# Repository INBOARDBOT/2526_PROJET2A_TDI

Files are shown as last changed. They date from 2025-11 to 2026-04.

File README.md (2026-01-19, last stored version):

# 2526_PROJET2A_TDI
Total Drive Immersion - Motion System

The objective of this project is to create a 3 axis motion plateform for car racing simulations.
It consist of four linear actuators (with their respective [**drivers**](https://github.com/INBOARDBOT/2526_PROJET2A_TDI/tree/main/HARDWARE/PCB'S/FOC_CONTROLLER_V2)), a Nucleo Discovery which handle
the communication between the drivers and the computer as well as a touchscreen interface.
The data is sent from SimHub to the the Nucleo via UART. The position values are then distributed to each actuator via an [**RS485**](https://github.com/INBOARDBOT/2526_PROJET2A_TDI/tree/main/HARDWARE/PCB'S/COM_BOARD) bus.

# Achitecture logicielle

L'architecture logicielle est conçue de manière modulaire, segmentant les fonctionnalités du simulateur de conduite en plusieurs sous-systèmes spécialisés. Cette approche permet de séparer les responsabilités et de faciliter la maintenance du système. L'architecture s'articule autour de trois piliers principaux :

Couche Communication : Gère les protocoles d'échange de données entre l'unité centrale et les drivers de vérins (via le bus RS-485), garantissant l'intégrité et la rapidité des transmissions.

Module de Gestion des Actionneurs : Assure le traitement des commandes, le calcul des trajectoires des vérins et le monitoring de l'état des drivers.

Interface Graphique et IHM : Pilote le rendu visuel sur l'écran LCD-TFT et traite les interactions tactiles de l'utilisateur, tout en gérant les ressources stockées en mémoire Flash.

## Organistaion du projet
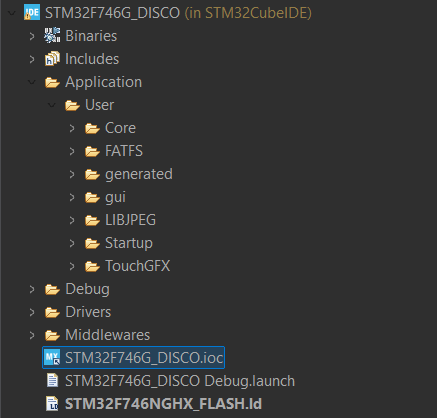
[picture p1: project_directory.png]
<br>
* `Application/` Contient la logique métier principale développée par l'utilisateur.
    * `gui/` et `generated/` Dédiés à l'interface graphique (typiquement pilotés par TouchGFX sur le F746G). Regroupe le backend (logique) et le frontend (assets et code généré).
    * `Core/` Noyau de l'application gérant la communication et la supervision de la centrale avec le reste du système de simulation.
* `Driver/` Regroupe les couches d'abstraction matérielle (BSP : gestion des composants externes). 
* `Debug/` Répertoire de sortie du compilateur.

## Présentation des Composants

### Unité Centrale
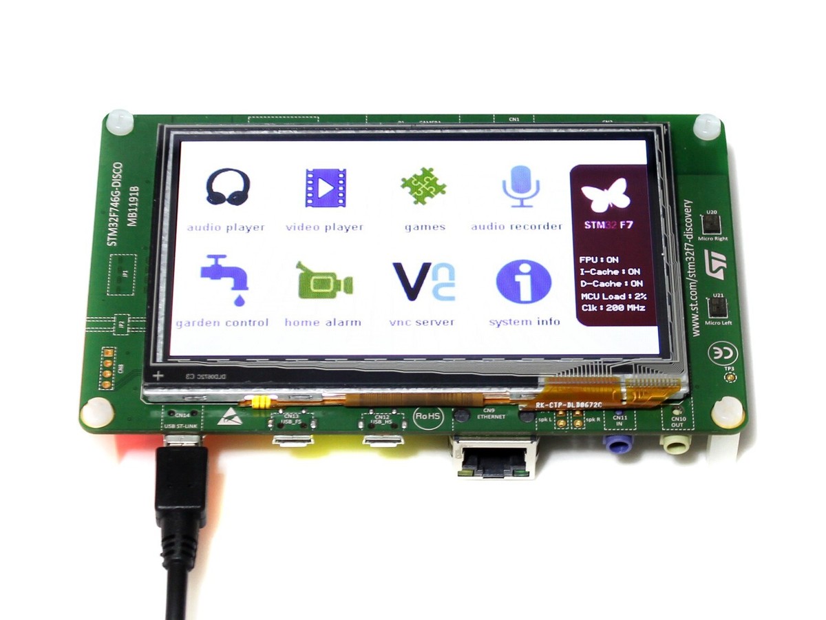
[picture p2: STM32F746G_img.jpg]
<br>
La centrale controle l'enssemble du systeme de simulation, elle doit etre reactive et embarquer une interface graphique servant d'IHM. Voici donc les principales fonctionnalites que la carte STM32F746G nous propose :
* Puissance de calcul : Architecture Arm Cortex STM32F746NGH6
* Interactions avec l'utilisateur (IHM) : Ecran tactile 4.3” RGB 480×272 color LCD-TFT
* Stockage des ressources graphiques lourdes commes les imges : 128-Mbit Quad-SPI Flash memory

Fonctionnalitees addiotionnelles petinentes :
* Gestion Audio intégrée : Audio line in and line out jack & Stereo speaker outputs

### Driver de vérin
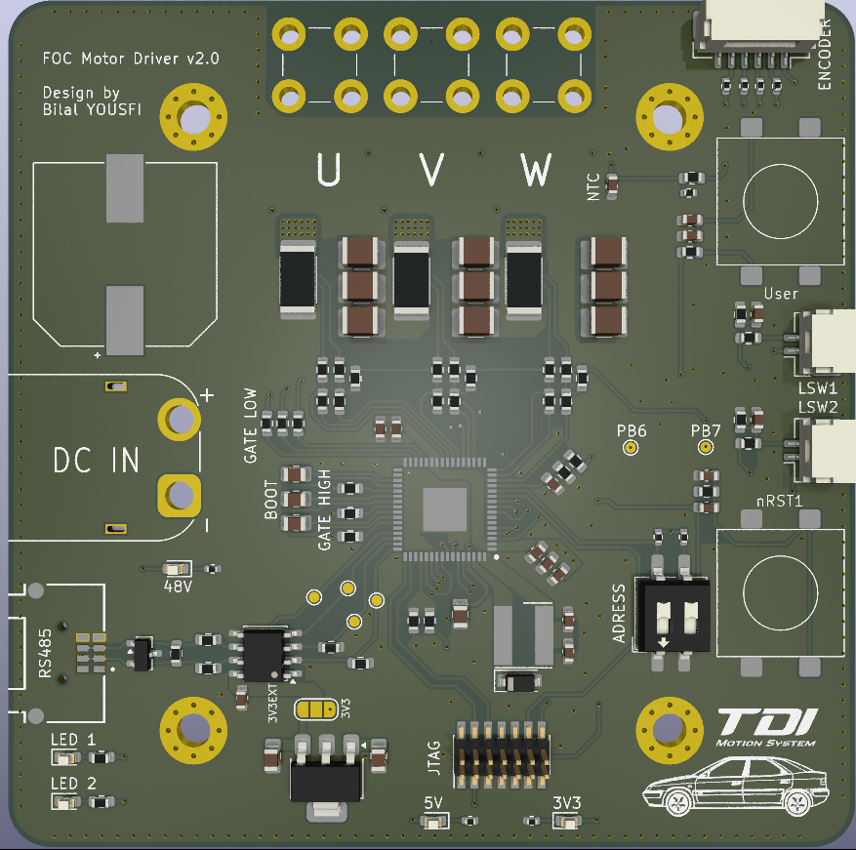
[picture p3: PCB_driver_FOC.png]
<br>
Les drivers des verrins permettent de faire l'interface entre les ordres transmis par la centrale et l'action entrepris par les verrins. 
Les drivers des verrins permettent de communiquer via le bus RS485 afin de recevoir les données de position et de renvoyer des informations sur l'etat de l'actionneur.Il est compose des elements suivants :
* STSPIN32G4: Gère les calculs d'asservissemntet  le controle de l'etage de puissance grâce a son driver de mosfet intégré.
* STL130N8F7: L'etage de puissance est composé de trois demi pont avec des N-MOS pouvant supporter jusqu'a 80V et 100A 
* THVD1420: Tranciever RS485 

### Interface de Communication (Bus RS-485)
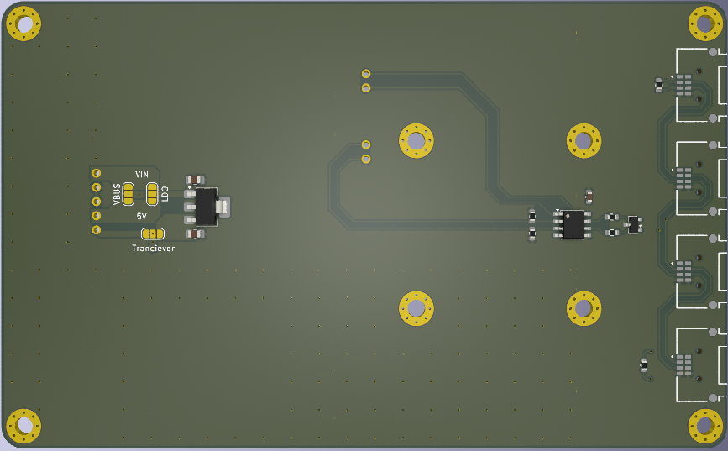
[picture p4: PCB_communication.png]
<br>
L'interface de communication est une carte électronique intermédiaire positionnée entre l'unité centrale et les différents actionneurs (vérins).

Pour surmonter la contrainte de la distance physique et garantir une transmission rapide et immunisée contre les parasites, la liaison s'appuie sur la norme RS-485. Ce standard utilise une signalisation différentielle particulièrement fiable en milieu industriel.

L'interface assure la conversion des signaux : elle transforme le protocole UART (TTL) de la centrale en signaux différentiels pour le bus, puis les drivers des vérins effectuent la conversion inverse pour traiter l'information. L'ensemble des drivers est raccordé en parallèle selon une topologie en bus, permettant une gestion simplifiée du câblage.

## Environnement de Développement
Le développement du projet repose sur une chaîne d'outils intégrée, permettant de gérer aussi bien la configuration matérielle que l'interface utilisateur et le versionnage du code.

`STM32CubeIDE` <br>
Il s'agit de l'environnement de développement (IDE) fourni par STMicroelectronics.

* Configuration : Intègre STM32CubeMX pour configurer graphiquement les périphériques (UART, RS-485, Horloges).

* Développement & Debug : Permet l'écriture du code en C/C++ et offre des outils de débogage avancés (lecture de registres en temps réel, analyseur de variables).

`TouchGFX Designer` <br>
Framework graphique avancé spécifiquement optimisé pour les microcontrôleurs STM32.

* Design UI : Permet de concevoir l'interface de manière visuelle pour ensuite developper en C++ dessus.

* CMSIS-RTOS : S'intègre avec FreeRTOS pour séparer le thread de rendu graphique des threads de communication et de calcul (Backend/Frontend).

* Generation du fichier du projet : Génére le code d'initialisation avec la configuration de l'interface graphique automatise (gros avantage de TouchGFX).

# Interface Graphique
<br>
L'interface graphique (IHM) permet de visualiser en temps réel l'état du système de simulation. Elle offre à l'utilisateur une plateforme interactive pour piloter le simulateur, lancer les procédures de calibration et ajuster les paramètres de conduite.

## TouchGFX Designer
TouchGFX Designer est l'outil utilisé pour concevoir l'environnement visuel. Il génère un code C++ optimisé qui tire parti des capacités d'accélération matérielle du STM32.

### Creation du projet
La première étape consiste à sélectionner le BSP (Board Support Package) correspondant à notre matériel : le `STM32F746G Discovery Kit`.<br>
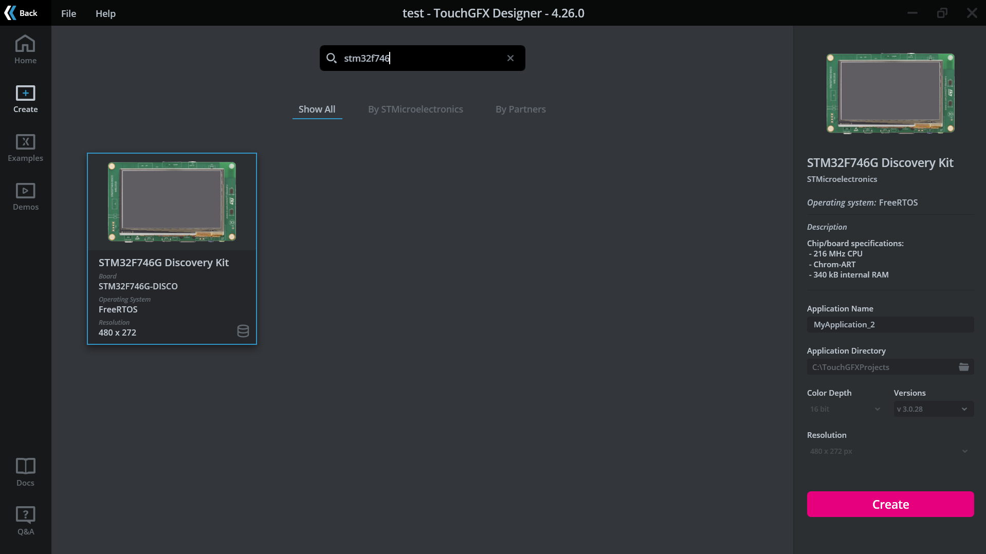
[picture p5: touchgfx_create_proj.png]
<br>

[!IMPORTANT] Cette étape est cruciale car TouchGFX génère non seulement l'interface, mais aussi toute la structure du projet (fichiers de configuration, drivers d'écran, gestion de la mémoire) que nous importerons ensuite dans STM32CubeIDE.

### Architecture de l'interface
L'interface est découpée en plusieurs Écrans (Screens). Chaque écran possède son propre fichier de vue (View) et son présentateur (Presenter), permettant de séparer la logique graphique de la logique métier.

#### Ecran
Les vues du simulateur
Pour garantir une navigation fluide, nous avons segmenté l'IHM en quatre écrans principaux :

* SimHubScreen : Le tableau de bord principal. Il affiche les données télémétriques en temps réel, telles que l'extension des vérins et la consommation électrique des drivers.

* LoadingScreen : Une interface de transition utilisée lors des processus lourds, typiquement durant la phase de calibration automatique des vérins.

* MenuScreen : Le point d'entrée central permettant à l'utilisateur de naviguer entre les différentes sections.

* SettingScreen : Un espace dédié à la configuration logicielle et matérielle du système.

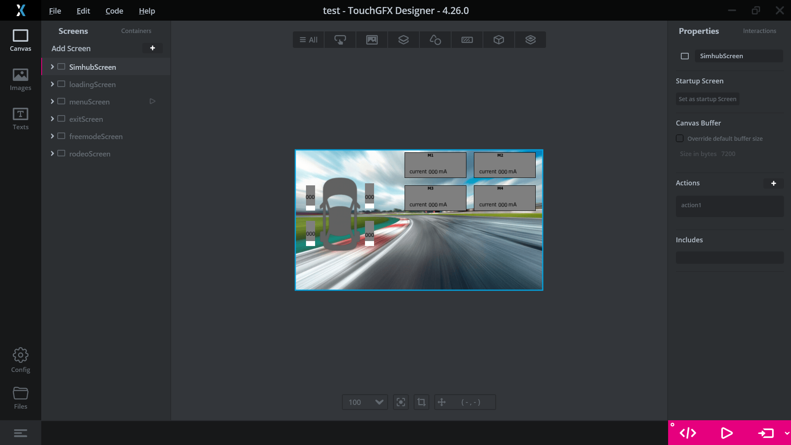
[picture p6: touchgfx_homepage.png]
<br>

Avoir une multitude d'ecran permet de faciliter le developpement des differents UI. 

#### Composants et Outils
L'IDE propose deux types de blocs de construction pour concevoir les écrans :

1. Les Widgets : Ce sont les éléments de base (boutons, zones de texte, jauges, formes géométriques). Ils sont entièrement personnalisables pour correspondre à la charte graphique du simulateur.

2. Les Conteneurs (Containers) : Ils permettent de regrouper plusieurs widgets au sein d'une même entité. Cela facilite la création de fenêtres modales, de listes déroulantes ou de menus complexes.

Vous pouvez retrouver ci-dessous la documentation sur les outils et conteneurs pour en apprendre d'avantages [Contenuer/Outil](https://support.touchgfx.com/docs/development/ui-development/working-with-touchgfx/widgets-and-containers)

### Generer le projet
Une fois le design finalisé, l'outil génère le code source. Ce processus inclut :

* La conversion des images en tableaux de données stockés en Flash QSPI.

* L'implémentation de l'API graphique compatible avec FreeRTOS.

* La configuration des périphériques de la carte (écran, tactile, DMA2D).

[!NOTE] Bien que TouchGFX Designer soit puissant, il se limite à la couche visuelle. Les interactions complexes (ex: cliquer sur un bouton pour activer un vérin) nécessitent une implémentation manuelle dans le code C++ généré, via des fonctions de rappel (Callbacks).

## Backend and Frontend communication
Le défi majeur consiste à faire communiquer l'interface utilisateur avec le reste du système (capteurs, bus RS-485). TouchGFX utilise une architecture structurée pour séparer l'affichage de la logique métier.<br>

Définitions
* Le Frontend (La Vue) : Comprend les composants visibles à l'écran. Il est responsable de l'affichage des données et de la capture des interactions utilisateur.

* Le Backend (Le Système) : Représente tout ce qui se passe en dehors de l'interface (réception des données RS-485, calculs de trajectoires, mesures de courant).

L'Architecture MVP (Model-View-Presenter)<br>
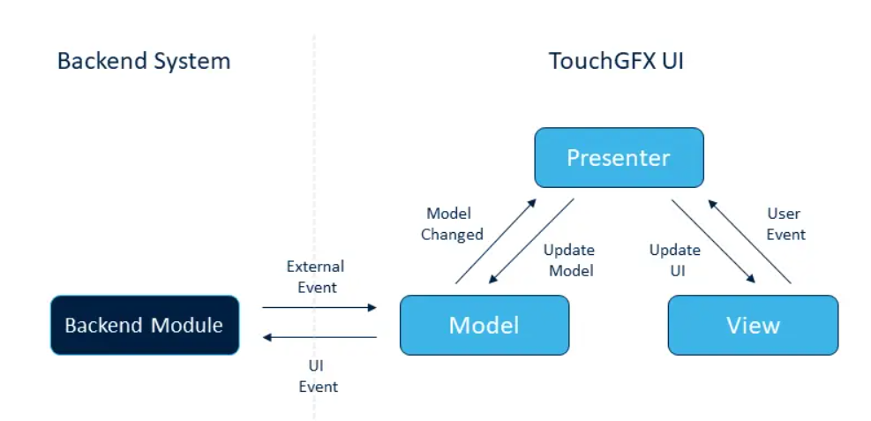
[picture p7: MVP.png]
<br>
Pour assurer une synchronisation fluide sans bloquer l'affichage, TouchGFX s'appuie sur trois couches :

1. Le Model : C'est le point d'entrée du Backend. Il reçoit les événements extérieurs (ex: nouvelle mesure de courant) et les stocke temporairement.

2. Le Presenter : Il agit comme un pont. Il surveille les changements dans le Model et ordonne à la View de se mettre à jour.

3. La View : Elle reçoit les ordres du Presenter et modifie visuellement les widgets (ex: mettre à jour la valeur d'une jauge).

vous pouvez visualiser cette video qui explique en detail comment afficher une valeur sur l'interface graphique [video](https://www.youtube.com/watch?v=Y7d6-59YQu8)

# Protocole de Communication
Comme expliqué précédemment, la liaison entre la centrale et les drivers repose sur une couche physique RS-485. Bien que les signaux en entrée et en sortie de l'interface soient au format UART, le support physique RS-485 permet de transporter ces données sur de longues distances tout en supportant une topologie réseau de type "Bus".

## Architecture Maître-Esclave
Pour organiser les échanges sur ce canal partagé, nous utilisons une architecture Maître-Esclave :

* Le Maître (Centrale) : Il est l'unique initiateur de la communication. Il interroge ou envoie des ordres aux drivers.

* Les Esclaves (Drivers) : Ils "écoutent" en permanence le bus et ne répondent ou n'agissent que lorsqu'ils sont explicitement sollicités par le maître.

## Principe du Bus de Communication 
Dans cette configuration, tous les esclaves sont branchés en parallèle sur la même ligne physique. Pour éviter que tous les vérins ne s'activent en même temps, nous utilisons un système d'adressage et de trames de données : <br>
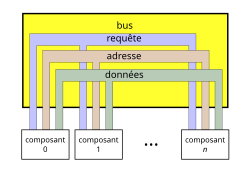
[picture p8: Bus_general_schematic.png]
<br>

1. L'Adressage : Chaque driver possède un identifiant unique (ID). Le message envoyé par la centrale commence par l'adresse de destination.

2. Le Filtrage : Tous les drivers reçoivent le signal, mais seul l'esclave dont l'adresse correspond à celle contenue dans le message traite l'information. Les autres ignorent la trame.

3. Les Données (Payload) : Une fois l'adresse validée, l'esclave décode les instructions (ex: consigne de position, vitesse, ou demande d'état).

## Gestion du flux (Half-Duplex)
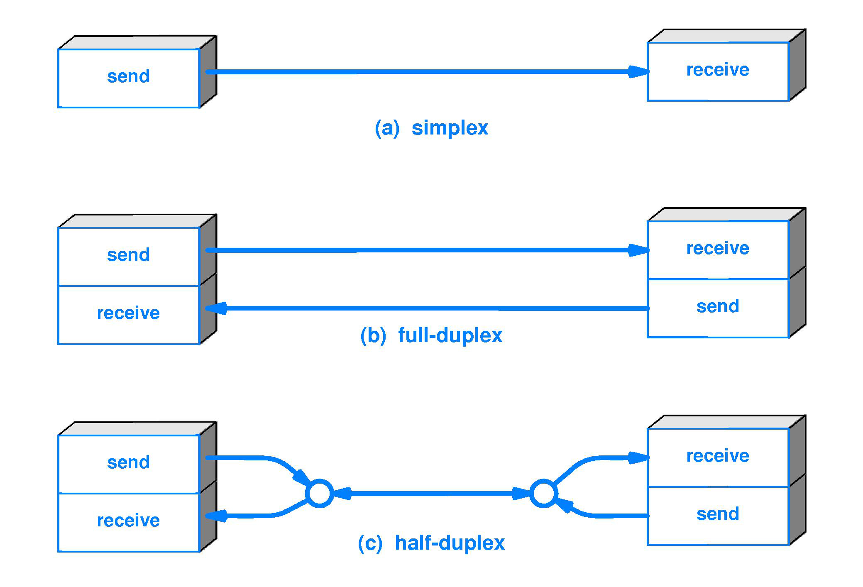
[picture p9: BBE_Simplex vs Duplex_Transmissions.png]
<br>
Le bus RS-485 utilisé est généralement Half-Duplex : la centrale et les drivers partagent la même paire de fils pour émettre et recevoir.

Point d'attention : La centrale doit libérer le bus (repasser en mode réception) immédiatement après avoir envoyé une commande pour permettre à l'esclave de renvoyer son accusé de réception ou ses données de télémétrie.

## Structure de communication
<p align="justify">Afin d'optimiser les échanges de données avec les quatre esclaves du système, nous utilisons un protocole de cycle séquentiel. Le maître initie une transmission/réception itérative de l'esclave 0 à l'esclave 3. Au cours de chaque cycle, le maître récupère l'intégralité des données de l'esclave ciblé et les traite avant de passer au suivant. </p>

### Paquet de Données
<p align="justify">Le paquet de données est l'élément central de notre protocole. Il agit comme un conteneur standardisé permettant de transporter efficacement les commandes et les retours d'état.</p>

Voici la structure logicielle du paquet :

```
typedef struct __attribute__((packed))
{
    uint8_t startByte;   
    uint8_t address;     
    uint8_t cycleId;     
    
    uint8_t statusFlags; 
    uint8_t payloadCount; 

    union {
        struct {
            uint8_t type;    
            uint8_t code;    
        } fifoEntries[MAX_DATA / 2];

        uint16_t infoArray[MAX_DATA / 2]; 
        
        uint8_t rawBytes[MAX_DATA];
    } payload;

    uint8_t checksum;
    uint8_t stopByte;    
} MotionPacket_t;
```

Caractéristiques de Transmission
* <p align="justify">Standard UART : Le type uint8_t est utilisé comme unité de base, conformément au standard de communication série UART.</p>

* <p align="justify">Résolution des données : Les données système (telles que celles fournies par SimHub) sont quantifiées sur 16 bits. Par conséquent, chaque valeur dans infoArray occupe deux octets (uint8_t) lors de la transmission série.</p>

### Flag 
Les `Flags` ou `Drapeaux` en francais sont des informations actuelles sur le systeme d'une longueur d'un seul bit. Voici les differents que s'echangent le master et les slaves.

_Flag Master_
| Flag info | Position bit  |
| --- |:---:|
| ACK_REQUEST | 0 |
| CYCLE_ID_RST  | 1 |
| EMPTY_DATA | 2 |
| TO_DEFINE | 3 |
| TO_DEFINE | 4 |
| TO_DEFINE | 5 |
| TO_DEFINE | 6 |
| TO_DEFINE | 7 |

EMPTY_DATA   : Inform the slave it doesn't need to look for data in the packet <br>
CYCLE_ID_RST : Inform the slave the cycle id is reset (to 0) <br>
ACK_REQUEST  : Inform the slave to respond with flag ACK <br>

_Flag Slave_
| Flag info | Position bit  |
| --- |:---:|
| ACK | 0 |
| INIT_DONE | 1 |
| MOTOR_EN | 2 |
| MOTOR_MOVING  | 3 |
| BUSY | 4 |
| EMPTY_DATA | 5 |
| EMPTY_STATUS  | 6 |
| TO_DEFINE | 7 |

ACK          : Inform the master that his message is acknowledged<br>
INIT_DONE    : Inform the master the initialisation is done (the system is calibrated)<br>
MOTOR_EN     : Inform the master that the motor are enabled to move<br>
MOTOR_MOVING : Inform the master the motor are moving<br>
BUSY         : Inform the master the slave can't take instruction at the moment<br>
EMPTY_DATA   : Inform the master to not look for data<br>
EMPTY_STATUS : Inform the master to not look for errors or events<br>

### Evenements
Les événements sont des alertes asynchrones envoyées par les esclaves pour informer d'un changement d'état opérationnel.<br>

Voici la liste evenements :
_Flag Slave_
| Evenement | Code |
| --- |:---:|
| EVT_NONE | 0x00 |
| EVT_MOVEMENT_STARTED | 0x01 |
| EVT_MOVEMENT_COMPLETED | 0x02 |
| EVT_TARGET_REACHED | 0x03 |
| EVT_LIMIT_SWITCH_MIN | 0x04 |
| EVT_LIMIT_SWITCH_MAX | 0x05 |
| EVT_HOMING_STARTED | 0x06 |
| EVT_HOMING_COMPLETED | 0x07 |
| EVT_DRIVER_ONLINE | 0x08 |
| EVT_DRIVER_OFFLINE | 0x09 |
| EVT_PARAM_CHANGED | 0x0A |
| EVT_PLAYMODE_ON | 0x0B |
| EVT_PLAYMODE_OFF | 0x0C |
| EVT_INITMODE_ON | 0x0D |
| EVT_INITMODE_OFF | 0x0E |
| EVT_SLEEPMODE_ON | 0x0F |
| EVT_SLEEPMODE_OFF | 0x10 |
| EVT_CALIB_STARTED | 0x11 |
| EVT_CALIB_COMPLETED | 0x12 |
| EVT_PARKED | 0x13 |

EVT_NONE : No event <br>              
EVT_MOVEMENT_STARTED : The slave piston has started its movement <br>  
EVT_MOVEMENT_COMPLETED : The slave piston has completed its movement<br>
EVT_TARGET_REACHED : The slave piston is a the requested position<br>    
EVT_LIMIT_SWITCH_MIN : The slave piston is at the minimum position<br>  
EVT_LIMIT_SWITCH_MAX : The slave piston is at the maximum position<br>  
EVT_HOMING_STARTED : The slave piston is performing homing<br>    
EVT_HOMING_COMPLETED : The slave piston has completed its homing<br>  
EVT_DRIVER_ONLINE : The slave is now offline wait to be restarted<br>     
EVT_DRIVER_OFFLINE : The slave is now online and can perform operation <br>     
EVT_PARAM_CHANGED : The slave has succesfully changed its parameter <br>     
EVT_PLAYMODE_ON : The slave is ready for gaming <br>     
EVT_PLAYMODE_OFF : The slave is not ready for gaming <br>     

### Erreurs
Les erreurs sont des alertes asynchrones signalant un dysfonctionnement ou une anomalie sur un esclave.<br>

Voici la liste erreurs :
| Erreur | Code |
| --- |:---:|
| ERR_NONE | 0x00 |
| ERR_INVALID_COMMAND | 0x01 |
| ERR_INVALID_PARAM | 0x02 |
| ERR_TIMEOUT | 0x03 |
| ERR_CHECKSUM_FAIL | 0x04 |
| ERR_UNSUPPORTED | 0x05 |
| ERR_STALL_DETECTED | 0x06 |
| ERR_UNDERVOLTAGE | 0x07 |
| ERR_UNDERVOLTAGEMCU | 0x08 |
| ERR_FAILED_CALIB | 0x09 |
| ERR_FAILED_SET_PIS_POS | 0x0A |
| ERR_COMM_LOST | 0x0B |
| ERR_FRAME_INVALID | 0x0C |
| ERR_OVERHEATING | 0x10 |
| ERR_OVERCURRENT | 0x11 |
| ERR_OVERVOLTAGE | 0x12 |
| ERR_OVERVOLTAGEMCU | 0x13 |

Les erreurs critiques se différencient par le préfixe 0x1-. Elles entraînent généralement une mise en sécurité immédiate du matériel.<br>

ERR_NONE : No error <br>
ERR_INVALID_COMMAND : Command instruction not found <br>    
ERR_INVALID_PARAM : Packet parameter is invalid <br>      
ERR_TIMEOUT : Slave sends it when it takes too much time to do an operation<br>            
ERR_CHECKSUM_FAIL : Checksum of packet failed <br>              
ERR_STALL_DETECTED : Piston does not move even though it is instructed to (physical struggle) <br>    
ERR_UNDERVOLTAGE : Piston under voltage <br>      
ERR_UNDERVOLTAGEMCU : MCU is under voltage <br>   
ERR_FAILED_CALIB : Slave failed calibration <br>      
ERR_FAILED_SET_PIS_POS : Slave failed to set to the correct position <br>
ERR_COMM_LOST : Slave lost communication with master <br>         
ERR_FRAME_INVALID : Packet structure is giberish <br>     
ERR_OVERHEATING : Critic error piston is over heating <br>       
ERR_OVERCURRENT : Critic error piston is short circuiting <br>       
ERR_OVERVOLTAGE : Critic error piston is over voltage <br>       
ERR_OVERVOLTAGEMCU : Critic error MCU is over voltage <br>    

### Commandes

Les commandes sont les mots cles dans les paquets de transmission d'informations entre la centrale et les drivers.<br>

Voici la liste des differentes commandes :
| Commandes | Code | User |
| :--- | :---: | :--- |
| CMD_NOP | `0x00` | Master |
| CMD_PING | `0x01` | Master |
| CMD_GET_INFO | `0x02` | Master |
| CMD_RETURN_INFO | `0x03` | Slave |
| CMD_SET_STATE | `0x04` | Master |
| CMD_SET_MOTOR | `0x05` | Master |
| CMD_SET_PISTON | `0x06` | Master |

CMD_NOP : No cmd <br>
CMD_PING : Ping driver, waits for ping back to verify communication. Possibility to add a custom message to pinged device. data(64B, optional) : char* <br>
CMD_GET_INFO : Master request data from driver. data(1B) :  <br> 
| Instruction | Position bit |
| --- |:---:|
| POSITION | 0 |
| SPEED | 1 |
| ACCELERATION | 2 |
| TEMPERATURE | 3 |
| MCU_VOLTAGE | 4 |
| DRIVER_VOLTAGE | 5 |
| DRIVER_STATE | 6 |
| UNDEFINED | 7 |
<br>

CMD_RETURN_INFO : Driver respond with requested data. data(14B) : <br>
| Instruction | Position byte  |
| --- |:---:|
| POSITION | 0-1 |
| SPEED | 2-3 |
| ACCELERATION | 4-5 |
| TEMPERATURE | 6-7 |
| MCU_VOLTAGE | 8-9 |
| DRIVER_VOLTAGE | 10-11 |
| DRIVER_STATE | 12-13 |
| UNDEFINED | --- |
<br>
Pay attention that the response uses a `variable-length packed format`. But the requested values are appended sequentially without gaps. For example, requesting only POSITION and DRIVER_STATE will result in a 4-byte payload where the state immediately follows the position.

CMD_SET_STATE : Set the state of the driver. IN (1B) :  <br> 
| Instruction | Position bit |
| --- |:---:|
| SLEEP | 0 |
| INIT | 1 |
| PLAY | 2 |
| UNDEFINED | 3 |
| UNDEFINED | 4 |
| UNDEFINED | 5 |
| UNDEFINED | 6 |
| UNDEFINED | 7 |
<br>

CMD_SET_MOTOR : Set the configuration of the motor. IN (1B) :  <br> 
| Instruction | Position bit |
| --- |:---:|
| MOTOR_ENABLE | 0 |
| MOTOR_MOVEMENT | 1 |
| UNDEFINED | 2 |
| UNDEFINED | 3 |
| UNDEFINED | 4 |
| UNDEFINED | 5 |
| UNDEFINED | 6 |
| UNDEFINED | 7 |
<br>

CMD_SET_PISTON : No cmd <br>

### Synchronizer les echanges
Le système de communication utilise un identifiant de synchronisation nommé `cycleId`. Cet octet permet de marquer chaque cycle de communication maître-esclave afin de s'assurer que tous les périphériques sont parfaitement synchronisés.<br>

Fonctionnement du CycleId
À chaque nouvelle interrogation de la chaîne d'esclaves (de 0 à 3), le Maître incrémente la valeur du cycleId. Cette valeur agit comme une horloge de synchonization temporel :

* Validation : L'esclave doit répondre en incluant le cycleId qu'il vient de recevoir.

* Détection de retard : Si un paquet esclave arrive avec un cycleId différent de celui attendu par le Maître, il est considéré comme obsolète ou corrompu.

* Intégrité temporelle : Cela évite que le Maître traite des données de télémétrie "anciennes" (provenant d'un cycle précédent) qui pourraient provoquer des saccades ou des erreurs de calcul dans le moteur de mouvement (Direct Drive ou Pistons).

### Queue slave
FIFO qui se remplie d'erreur et d'evenement, se vide a chaque fois que slqve envoie un packet au master.

### Recapitulatif
Master - Slave synchonization cycle  
Diagram Name

## Synchroniser le systeme
[!En cours de developpement]

### FSM du systeme
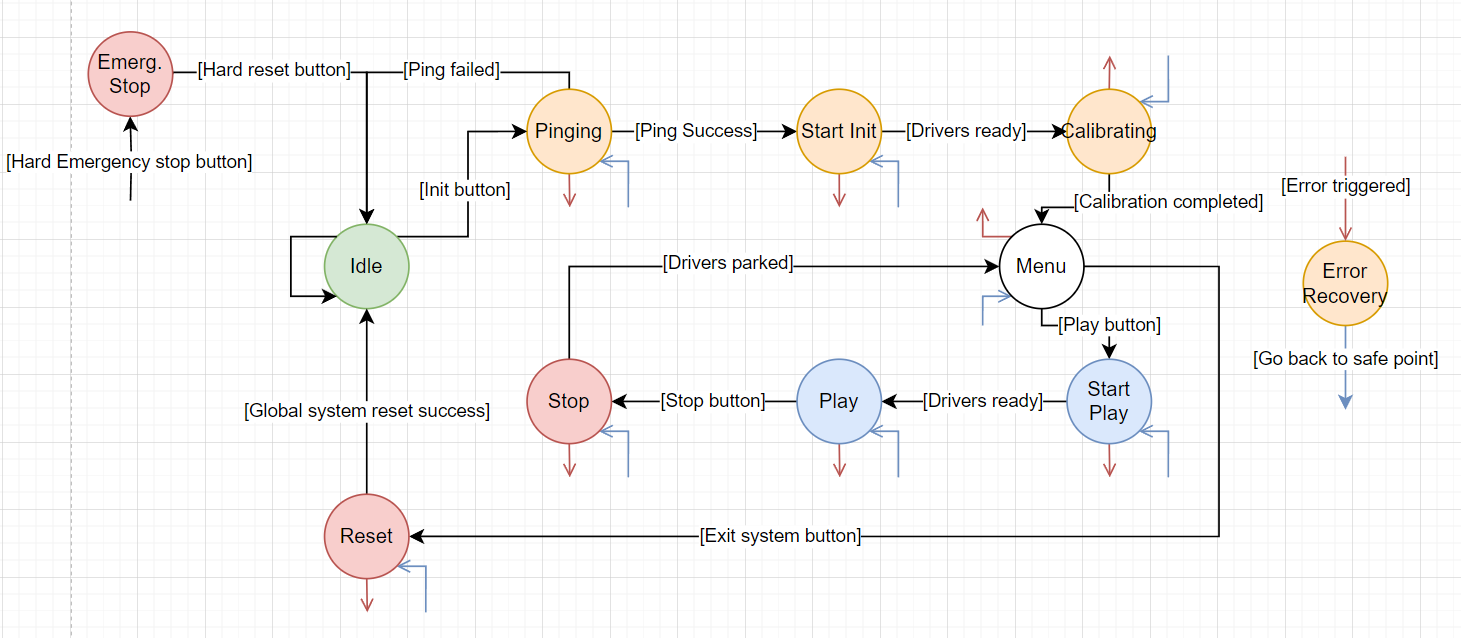
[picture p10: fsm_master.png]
<br>

#### Les etats de base 

#### Error Recovery

### FSM du protocole de communication
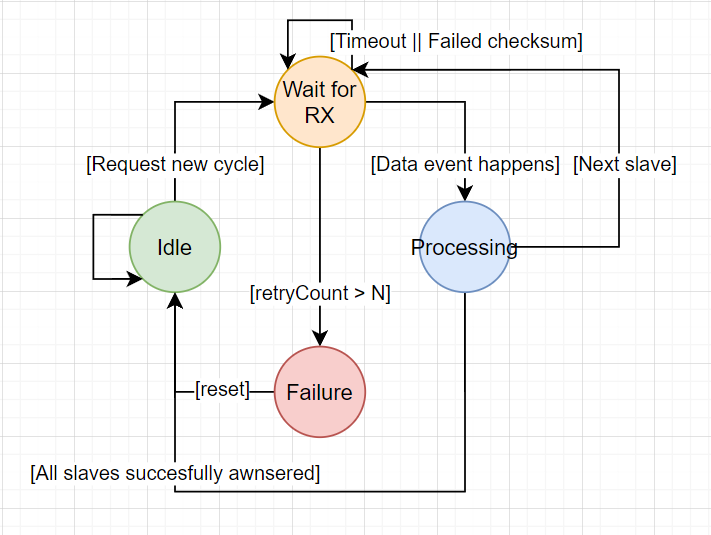
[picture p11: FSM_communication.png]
<br>

#### TimeOut

### Synchronisation des deux FSM

#### variable `extern`
#### Statue des drivers

### Traiter les informations ascendantes (cote centrale)

## Synchronisation avec l'API graphique

### Gestion des Tâches (RTOS)

### Synchronisation de thread

#### Semaphore

# Manipuler SimHub
SimHub agit comme une passerelle (middleware) entre les jeux de course (Assetto Corsa, iRacing, etc.) et notre simulateur. Il extrait la télémétrie physique pour la convertir en consignes de mouvement.
## Motion output
L'onglet Motion Output est le cœur de la communication. Il permet de définir le protocole série personnalisé qui sera interprété par la carte STM32.
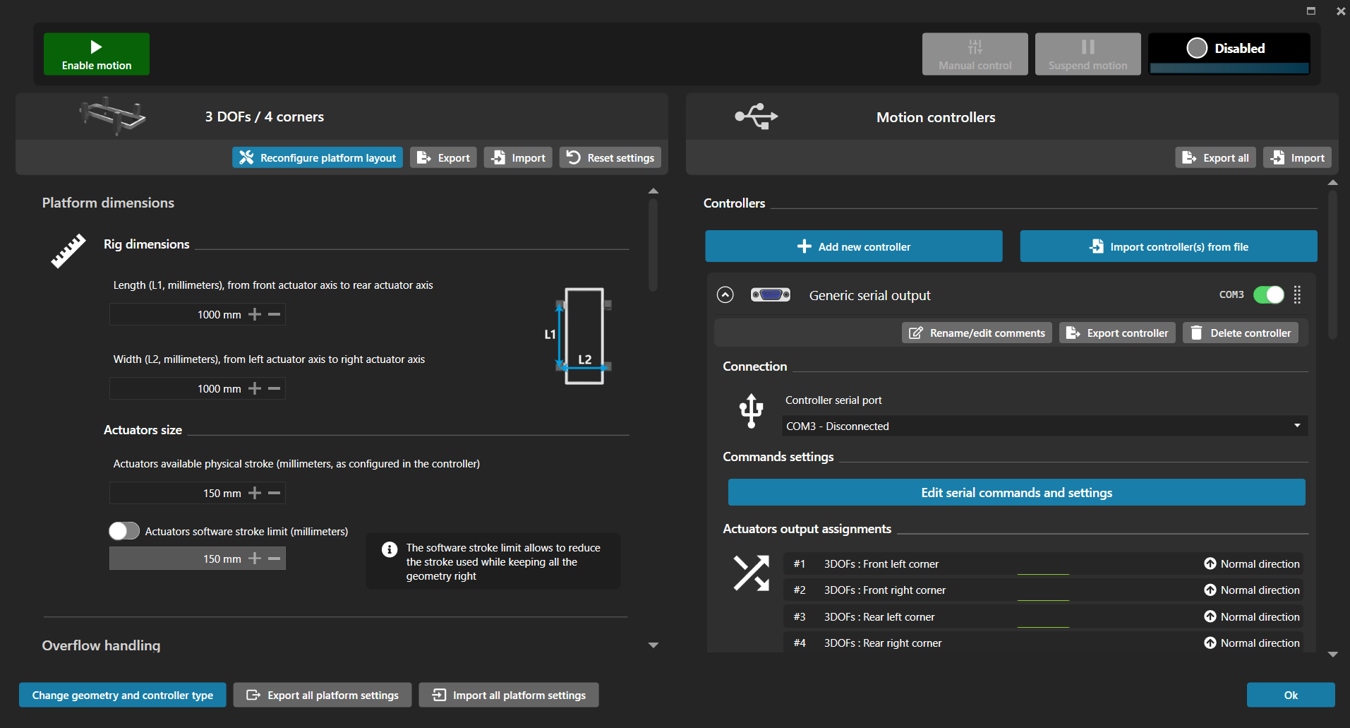
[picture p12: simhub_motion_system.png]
SIMHUB MO

### Parametres de communication
Pour garantir une synchronisation parfaite entre SimHub et le STM32F746G, les réglages suivants sont appliqués :

* Encapsulation : Utilisation d'un caractère de début (0x44 / 'D') et de fin (0x45 / 'E').

* Résolution : Données sur 16 bits (Binary) pour une précision optimale des axes (Pitch, Roll, Yaw, Heave).

* Baudrate : Configuré pour minimiser la latence (ex: 115200 ou 256000 bauds).
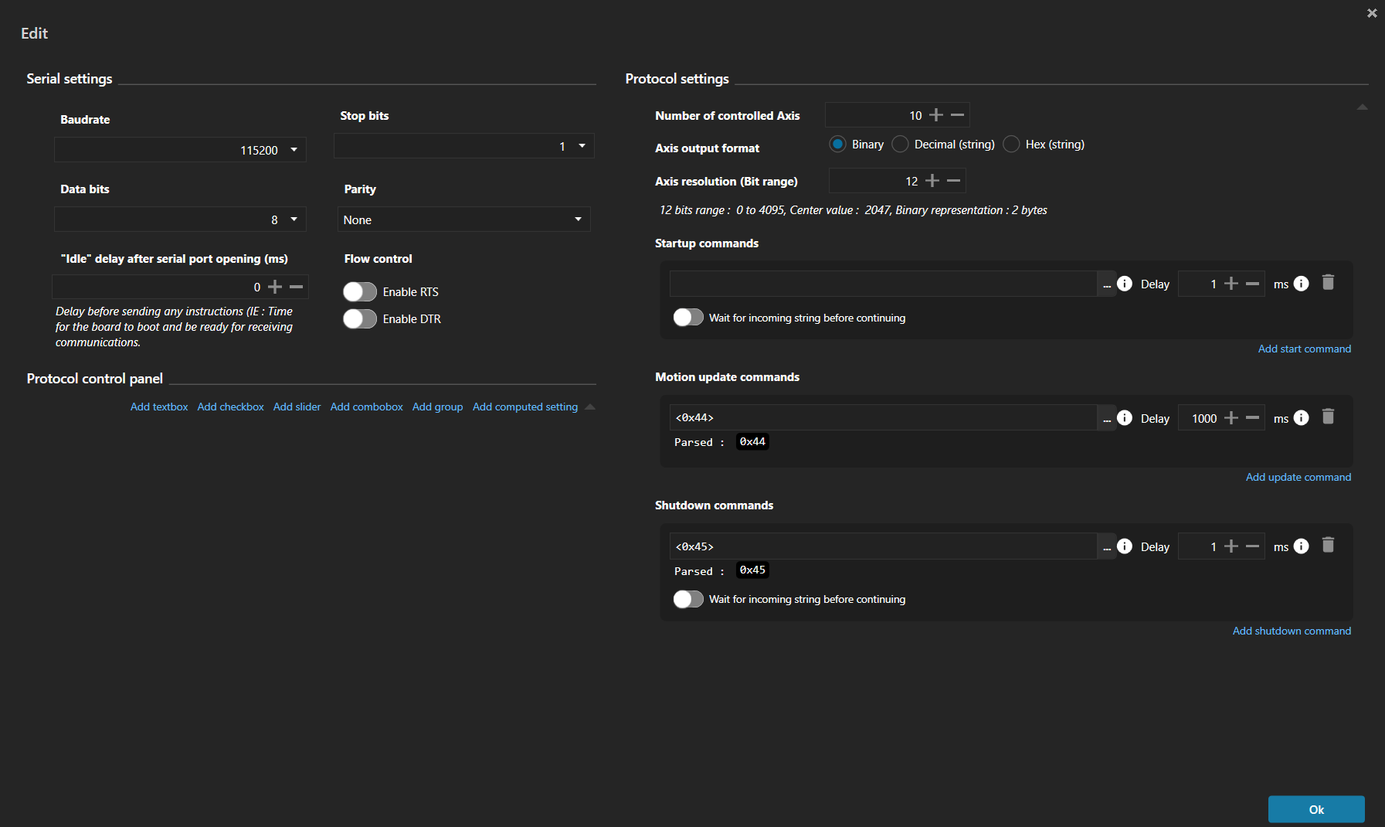
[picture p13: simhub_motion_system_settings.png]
SIMHUB MO SETTINGS

### Simple configuration UART
Le STM32F746G reçoit le flux binaire en mode Polling pour une simplicité de traitement immédiate, sans la latence liée à la gestion des tampons DMA complexes dans ce contexte de simulation temps réel.<br>
#### Configuration du port de communication serie
Le port UART7 est configuré en mode asynchrone. L'horloge du périphérique est ajustée pour supporter les transferts rapides nécessaires au rafraîchissement des moteurs.
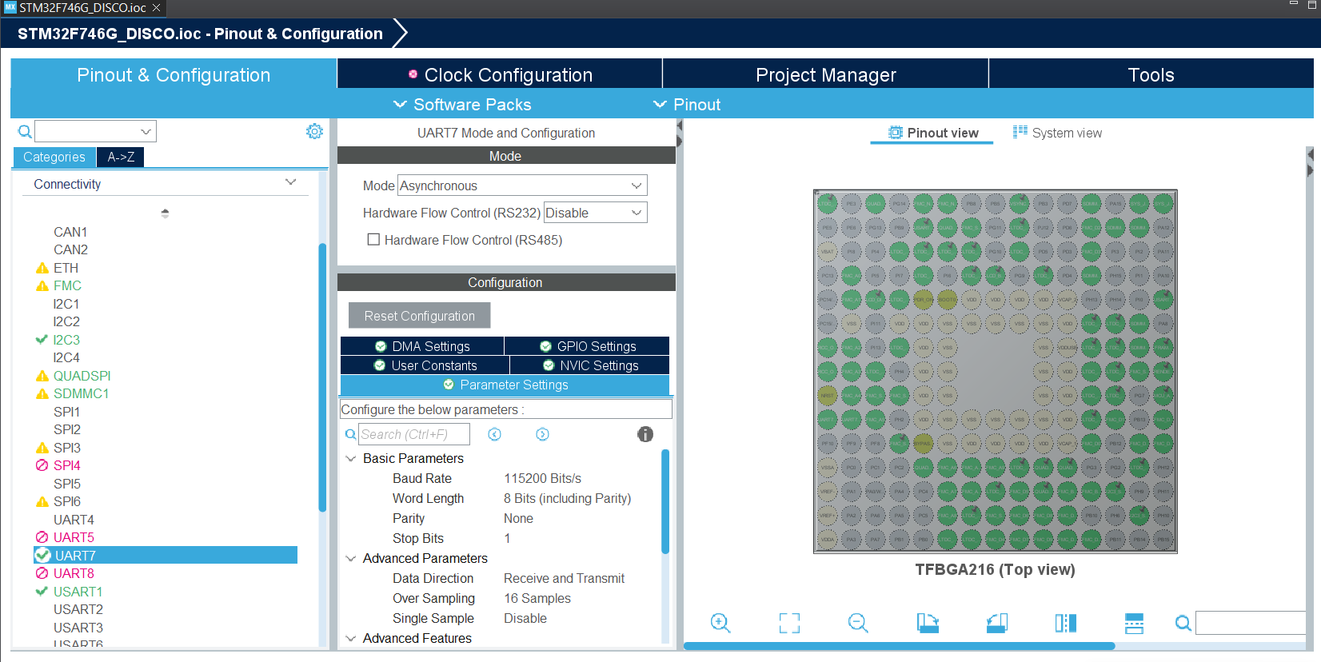
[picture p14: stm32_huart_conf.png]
<br>

#### Code simple de reception
Le code suivant surveille le registre ISR (code non-bloquant) de l'UART pour capturer la trame de 8 octets (4 axes x 16 bits) envoyée par SimHub.
```
#include "main.h"

uint16_t sensorData[4];
uint8_t tempBuffer[8];
int byteCount = 0;
bool syncFound = false;

void Update_UART_Communication(void) {
    if (UART7->ISR & USART_ISR_RXNE) {
        uint8_t receivedByte = (uint8_t)(UART7->RDR); 

        if (receivedByte == 0x44) {
            syncFound = true;
            byteCount = 0;
        } 
        else if (receivedByte == 0x45 && syncFound) {
            if (byteCount == 8) {
                for (int i = 0; i < 4; i++) {
                    sensorData[i] = (uint16_t)(tempBuffer[i*2] | (tempBuffer[i*2+1] << 8));
                }
                // Traitement des données ici
            }
            syncFound = false;
        } 
        else if (syncFound) {
            if (byteCount < 8) {
                tempBuffer[byteCount++] = receivedByte;
            } else {
                syncFound = false;
            }
        }
    }
}

int main(void) {
    // Initialisation HAL...
    
    while (1) {
        Update_UART_Communication();
    }
}
```

# Resources 
Documentation de la carte STM32F746G [link1](https://www.st.com/en/evaluation-tools/32f746gdiscovery.html#st_description_sec-nav-tab) <br>
Documentation de l'API graphique TouchGFX [link2](https://support.touchgfx.com/docs/introduction/welcome)<br>
Documentation RTOS sur la synchronization de threads [link3](https://arm-software.github.io/CMSIS_5/RTOS/html/cmsis__os_8h.html)<br>

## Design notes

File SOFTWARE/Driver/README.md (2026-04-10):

# 2526 · PROJET 2A · TDI
> **Total Drive Immersion** — Système de plateforme à motion

---

## Présentation

Ce dépôt contient le firmware du **driver** de la plateforme TDI. Le driver est le maillon qui traduit les consignes reçues depuis la centrale en commandes concrètes pour faire bouger la plateforme. Il tourne sur un microcontrôleur STM32 et gère l'ensemble de la chaîne : mesure des capteurs, contrôle moteur FOC, communication et supervision système.

---

## Architecture du code

```
.
├── Drivers/              # Librairies bas-niveau (ARM Math DSP, HAL STM32)
└── Core/
    ├── inc/              # Fichiers d'en-tête générés
    ├── src/              # Fichiers source générés
    ├── startup/          # Fichiers de démarrage générés
    └── lib/
        ├── application/  # Couche applicative (centrale, pyGraph, supervision globale)
        ├── filters/      # Filtres pour l'estimation correcte des capteurs
        ├── FOC/          # Contrôle moteur (Field-Oriented Control)
        ├── peripherals/  # Configuration et pilotage des capteurs
        ├── PID/          # Correcteurs PID
        └── test/         # Fichiers de test des différents sous-systèmes
```

---

## Configuration matérielle (IOC)

### Cahier des charges du MCU

| Fonction | Description |
|---|---|
| Mesure de courant | Sur les trois phases moteur via résistances shunt |
| Mesure de tension bus | Vbus sur ADC1 rang 1 |
| Position angulaire | Encodeur incrémental en quadrature (A, B, Z) |
| Communication | LPUART via ST-LINK (prog / debug / release) |
| Contrôle moteur | PWM triphasé (BLDC) |

---

## Timers

### TIM1 — Synchronisation principale
Timer haute priorité, cœur du système temps réel.

- **CH1/CH1n, CH2/CH2n, CH3/CH3n** : signaux PWM triphasés envoyés au moteur BLDC.
- **CH4** (sans sortie physique) : référence de synchronisation — déclenche la mesure de courant sur l'injecteur ADC via *toggle on match*.

La fréquence PWM est configurable directement via les registres `ARR` et `PSC`.

### TIM2 — Correcteur vitesse *(à implémenter)*
Timer logiciel cadencé à **500 Hz**, destiné au correcteur en vitesse. Non encore implémenté.

### TIM3 — Mode encodeur
Aucune horloge de référence interne. Le compteur est incrémenté par l'encodeur externe raccordé en quadrature (fronts montants et descendants sur les signaux **A** et **B**). Le signal **Z** déclenche une interruption GPIO à chaque révolution complète.

---

## Sources d'interruption (ISR)

| Fonction | Déclencheur | Rôle |
|---|---|---|
| `HAL_GPIO_EXTI_Callback()` | Signal Z encodeur | Détection d'une révolution complète |
| `HAL_TIM_PeriodElapsedCallback()` | Débordement timer | Appel périodique selon la config du timer |
| `HAL_ADCEx_InjectedConvCpltCallback()` | TIM1 CH4 toggle | Mesure de tension aux bornes de la résistance shunt |

---

## Chaîne de mesure du courant

### 1 · OPAMP (amplification)
Les OPAMPs internes au MCU amplifient la tension aux bornes des résistances shunt. Cette tension étant très faible, elle ne serait pas correctement résolue par l'ADC sur sa plage [0 V, 3,3 V] sans amplification.

Mode utilisé : **PGA à connexion interne** — gain configurable en puissance de 2, montage différentiel avec rebouclage sur l'entrée inverseuse, sortie simultanément lisible par l'ADC.

### 2 · ADC (conversion)
- Résolution : **12 bits**
- Cycle de traitement : **6,5 cycles** (compatible avec un délai d'interruption de 100 µs)
- Déclenchement : `TIM1 CH4 toggle on match`
- Lecture : directement depuis les registres ADC

| ADC | Rang 1 | Rang 2 |
|---|---|---|
| `ADC1` | Mesure Vbus | Mesure Vshunt phase C |
| `ADC2` | Mesure Vshunt phase B | Mesure Vshunt phase A |

---

## GPIO

| Signal | Direction | Description |
|---|---|---|
| Adresse 2 bits | Entrée | Identifiant matériel du driver |
| Bouton utilisateur | Entrée | Interaction manuelle |
| LEDs (hors alimentation) | Sortie | Indicateurs d'état |
| Signal Z encodeur | Entrée + IRQ | Détection révolution complète |

---

## Communication

**LPUART** — liaison série basse consommation via le connecteur ST-LINK embarqué.
Utilisée pour la programmation, le débogage et la mise en production.

# Capteurs & Contrôleurs
> Documentation technique du firmware TDI — couche mesure et régulation

L'ensemble des capteurs sont configurés dans leurs propres fichiers, regroupés dans `peripherals/`.

---

## Mesure du courant

La mesure est effectuée toutes les **100 µs**, synchronisée sur la fin du signal PWM. À cet instant précis, une seule porte du demi-pont supérieur est fermée et deux portes du demi-pont inférieur sont fermées — c'est la fenêtre idéale pour une mesure propre, sans bruit de commutation.

On mesure directement **Ia** (en phase) et **Ib** (déphasé de π/3), puis **Ic** est déduit par la loi des nœuds :

```
Ic = -(Ia + Ib)
```

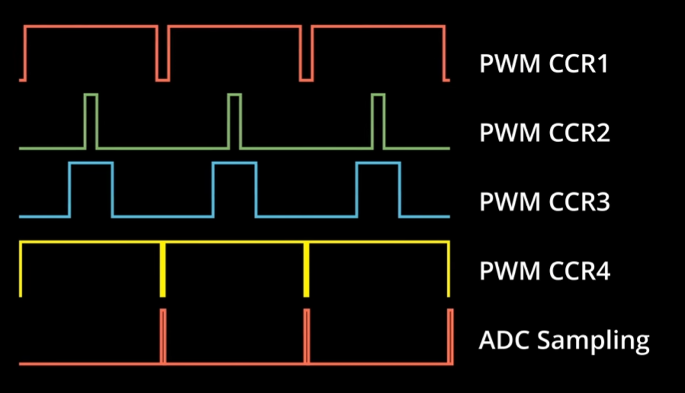
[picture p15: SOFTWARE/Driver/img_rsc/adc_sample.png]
Fenêtre d'échantillonnage ADC


### Conversion tension → courant

La formule théorique est :

```
I = Vbus × valeur_ADC / ((2¹² - 1) × gain_PGA × gain_externe × R_shunt)
```

En pratique, les résultats obtenus avec cette formule étaient aberrants — les courants calculés évoquaient davantage un four à induction industriel qu'un moteur BLDC 24 V. Les valeurs de gain réelles du circuit ne correspondaient pas aux valeurs nominales.

**Solution adoptée :** calibration expérimentale. Des courants connus ont été injectés via un générateur de courant, et les valeurs ADC correspondantes ont été relevées. La relation linéaire obtenue sert de référence de conversion.

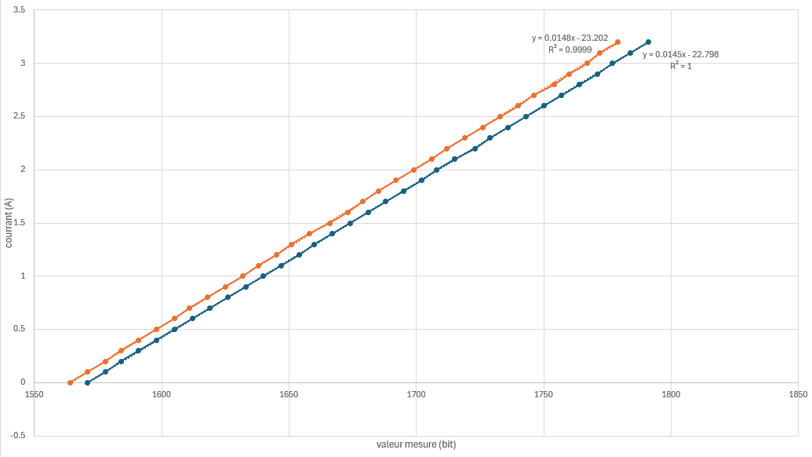
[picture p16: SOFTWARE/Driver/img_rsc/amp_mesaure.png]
Courbes de calibration courant/ADC


L'exploitation de ces courbes est détaillée dans la section *Contrôleur courant*.

---

## Mesure de la position instantanée

L'encodeur incrémental compte les impulsions des signaux **A** et **B** en quadrature. À chaque révolution complète, le signal **Z** se déclenche et le compteur revient à 0. Le timer TIM3 est configuré avec `ARR = 4095` pour correspondre exactement à cette plage.

La conversion en radians est directe :

```
θ = valeur_mesurée / 4095 × 2π
```

### Mesure de la vitesse

La vitesse angulaire est calculée par différence de position sur une fenêtre temporelle fixe :

```
ω = Δθ / Δt       avec Δt = 2 ms  (cadence 500 Hz)
```

La cadence de 500 Hz est délibérément plus lente que la mesure de courant (10 kHz). À 10 kHz, la variation de position entre deux échantillons vaut systématiquement 1 pulse — la mesure serait saturée et inutilisable. À 500 Hz, la variation est suffisamment grande pour être significative tout en restant réactive.

---

## Mesure de la tension de bus

La conversion est simple car il n'y a pas de shunt ni d'amplification différentielle — la tension de bus est divisée par un pont résistif directement lisible par l'ADC :

```
V_bus = valeur_ADC / (2¹² - 1) × V_ref
```

---

## Contrôleurs

Les contrôleurs corrigent les écarts entre la consigne et la mesure réelle. Ils sont organisés en trois boucles imbriquées, du plus rapide au plus lent : **courant → vitesse → position**.

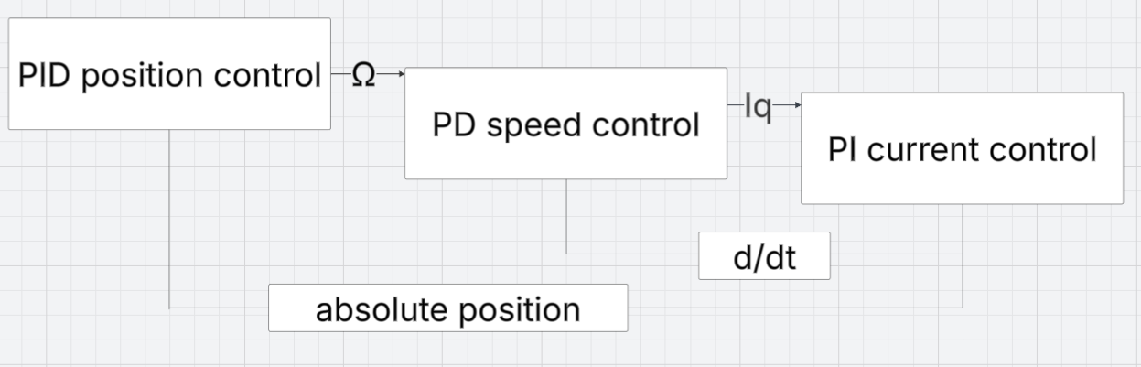
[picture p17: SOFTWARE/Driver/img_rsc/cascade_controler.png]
Correcteur en cascade


---

## Contrôleur courant

C'est la boucle la plus rapide et la plus critique du système. Elle s'exécute à **10 kHz** (toutes les 100 µs) et garantit que le moteur ne surconsomme pas, quelle que soit la consigne de couple.

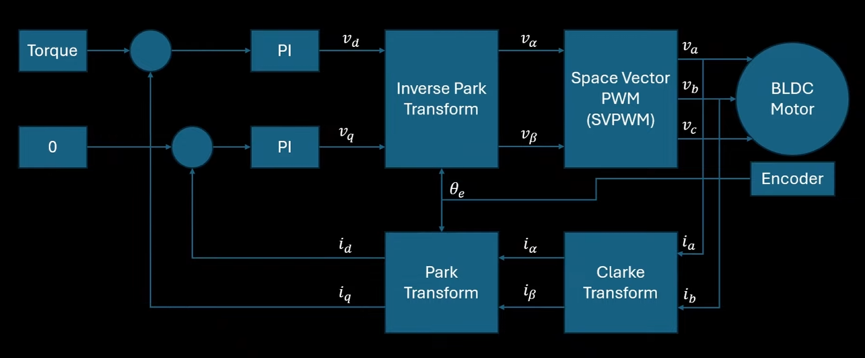
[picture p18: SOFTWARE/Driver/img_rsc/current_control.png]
Current Control


### Transformées de Clarke et Park

Le moteur BLDC génère des grandeurs triphasées sinusoïdales (Ia, Ib, Ic) qui varient en permanence avec la position du rotor. Pour appliquer un correcteur simple et stable, on projette ces grandeurs dans un repère fixe puis tournant.

**Transformée de Clarke** (3 phases → 2 axes fixes α/β) :

```
Iα =  Ia
Iβ = (Ia + 2·Ib) / √3
```

Cette étape réduit le système triphasé à deux composantes orthogonales dans un repère stationnaire lié au stator.

**Transformée de Park** (axes fixes α/β → axes tournants d/q) :

```
Id =  Iα·cos(θ) + Iβ·sin(θ)
Iq = -Iα·sin(θ) + Iβ·cos(θ)
```

En se plaçant dans le repère lié au rotor (qui tourne à la même vitesse que le champ magnétique), **Id** et **Iq** deviennent des grandeurs continues en régime permanent. Id contrôle le flux (maintenu à 0 pour un BLDC), Iq contrôle le couple. On peut donc leur appliquer des correcteurs PI classiques.

### SVPWM — Space Vector PWM

Une fois les tensions de commande Vd et Vq calculées par les PI, on applique la transformée inverse de Park pour revenir en α/β, puis le **SVPWM** génère les rapports cycliques des trois phases.

Le SVPWM décompose le vecteur tension souhaité (Vα, Vβ) en une combinaison pondérée de deux vecteurs actifs adjacents parmi les six vecteurs de base de l'onduleur, complétée par des vecteurs nuls. L'avantage par rapport à un simple sinus de référence est une meilleure utilisation de la tension de bus (facteur ~1,15) et une symétrie des commutations qui réduit les harmoniques.

### Correcteur PI

Le correcteur utilisé est un **Proportionnel-Intégrateur** :

```
u(t) = Kp·e(t) + Ki·∫e(t)dt
```

- Le terme **proportionnel** assure la réactivité.
- Le terme **intégrateur** élimine l'erreur statique en régime permanent.
- Pas de terme **dérivateur** : une variation brusque du courant génère un pic d'erreur dérivée qui déstabilise le correcteur — la boucle courant est déjà suffisamment rapide sans lui.

---

## Contrôleur vitesse

> *En cours de développement.*

---

## Contrôleur position

> *En cours de développement.*

---

## Test en boucle ouverte

Le test en boucle ouverte permet de valider le bon fonctionnement des capteurs et de la chaîne de commande **avant** de fermer les boucles de régulation. C'est l'étape de vérification indispensable avant toute mise en régulation.

**Ce qu'on vérifie :**

| Signal | Comportement attendu |
|---|---|
| Position encodeur | Alignée avec la consigne angulaire imposée |
| Courant mesuré | Forme d'onde caractéristique SVPWM (créneaux modulés) |

Si l'encodeur ne suit pas la consigne ou si le courant présente des distorsions anormales, le problème vient de la configuration matérielle (polarité shunt, sens encodeur, offset ADC) et doit être corrigé avant d'activer les correcteurs.

# Resources 
Documentation STM32G431VBT [link1](https://www.st.com/en/evaluation-tools/32f746gdiscovery.html#st_description_sec-nav-tab) <br>
Documentation OPAMPs [link2](https://support.touchgfx.com/docs/introduction/welcome)<br>
Documentation ADCs [link3](https://arm-software.github.io/CMSIS_5/RTOS/html/cmsis__os_8h.html)<br>
Documentation schema EVLSPIN32G4-ACT [link4](https://www.st.com/resource/en/schematic_pack/evlspin32g4-act-schematics.pdf)<br>
ARM math library [link5](https://arm-software.github.io/CMSIS_5/DSP/html/index.html)<br>
HAL libraries [link6](https://sourcevu.sysprogs.com/stm32/HAL/symbols/HAL_ADCEx_InjectedStart_IT)<br>
The goat SIROJU [link7](https://github.com/sirojudinMunir/stm32-FOC)<br>

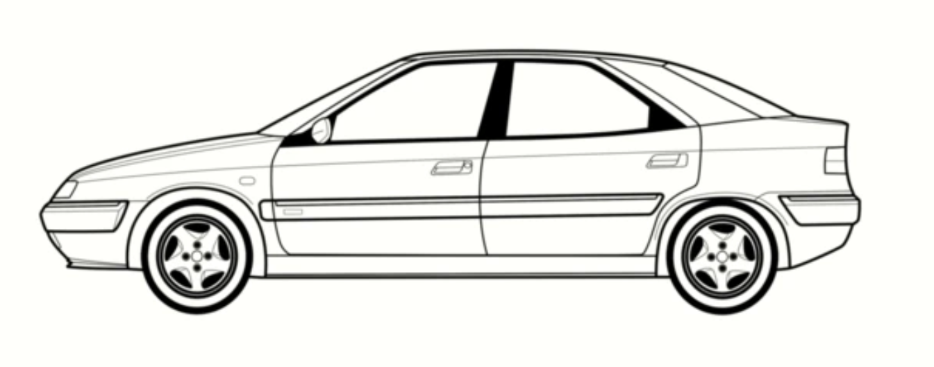
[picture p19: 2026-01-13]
HARDWARE/PCB'S/FOC_CONTROLLER_V2/Custom_lib/Graphics/Xantia.png

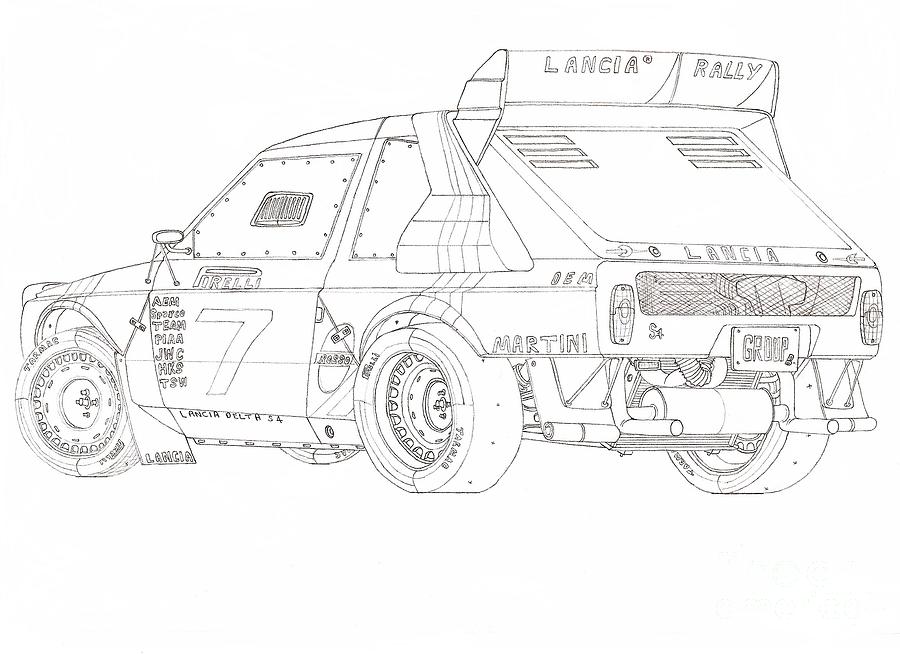
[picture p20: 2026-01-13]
HARDWARE/PCB'S/FOC_CONTROLLER_V2/Custom_lib/Graphics/lancia-delta-s4-group-b-rally-car-kaan-ipek.jpg

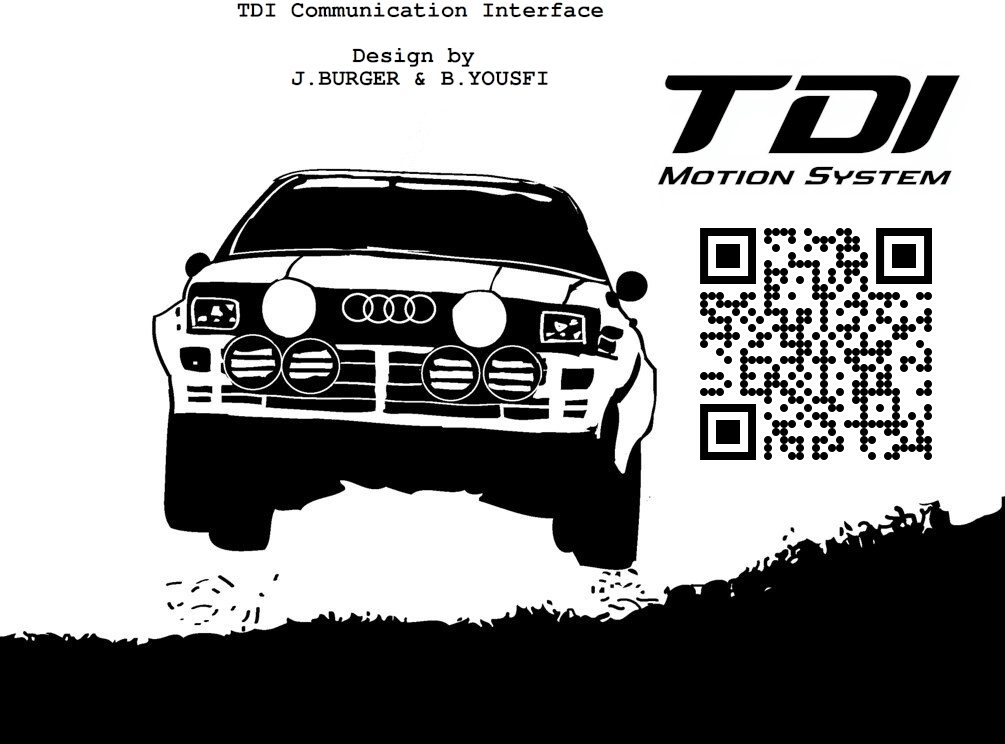
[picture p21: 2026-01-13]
HARDWARE/PCB'S/COM_BOARD/Custom/Graphics/audi qr.jpg

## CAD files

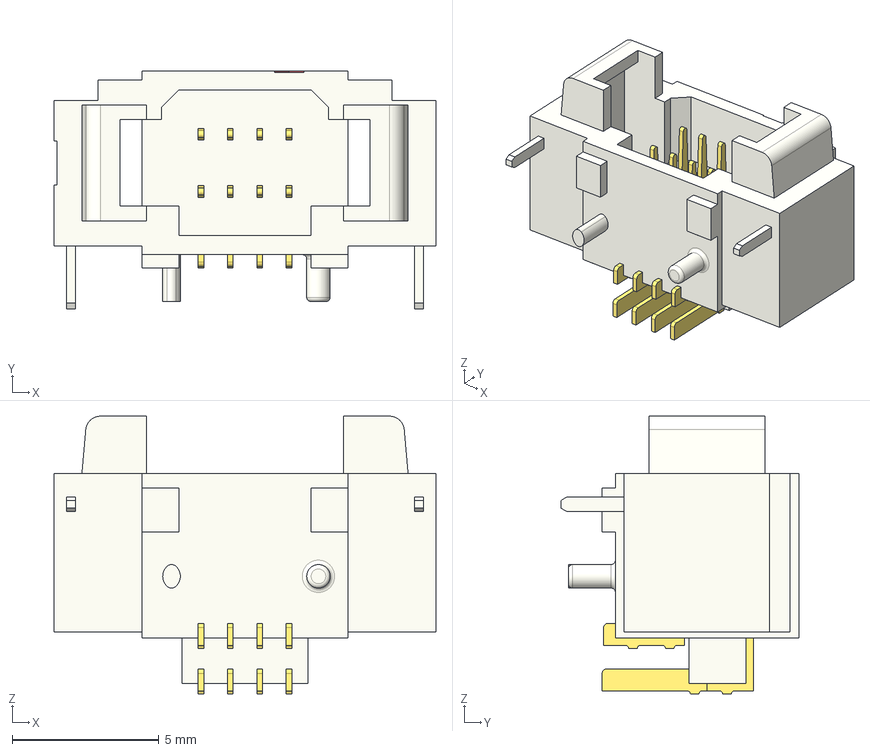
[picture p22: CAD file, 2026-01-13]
HARDWARE/PCB'S/COM_BOARD/Custom/3D/T1M-04-GF-DH.stp
13.0 x 8.10 x 9.45 mm
T1T1M-04-T-DH
P2T1M-04-GF-DH
P22T1M-04-GF-DH

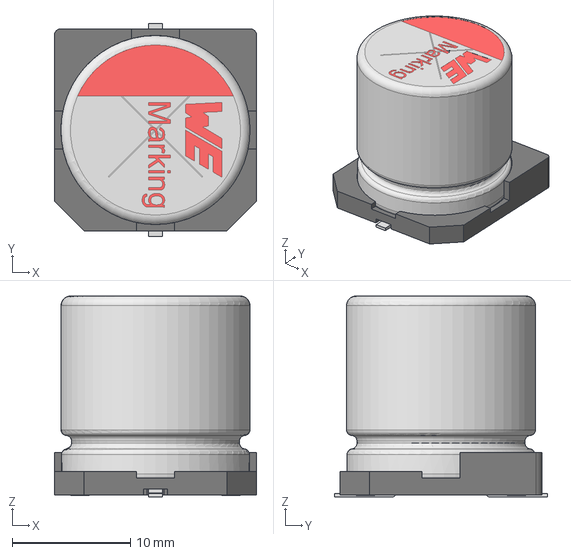
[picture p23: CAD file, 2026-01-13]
HARDWARE/PCB'S/FOC_CONTROLLER_V2/Custom_lib/3D/WCAP-ASLL Aluminum 16x17.stp
17.1 x 18.0 x 17.0 mm
Base_Φ16Capacitor
capicitor_16x17x6.6

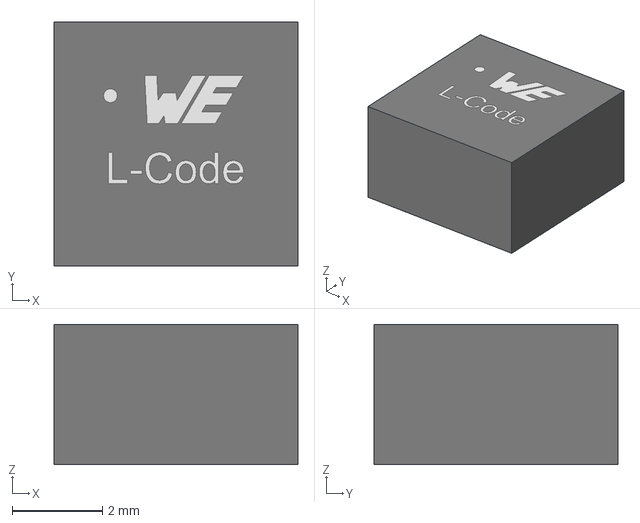
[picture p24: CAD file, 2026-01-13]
HARDWARE/PCB'S/FOC_CONTROLLER_V2/Custom_lib/3D/STP_WE-MXGI_5030 (rev1).stp
5.40 x 5.40 x 3.10 mm
body_SSMC_5030
land_pattern x 2

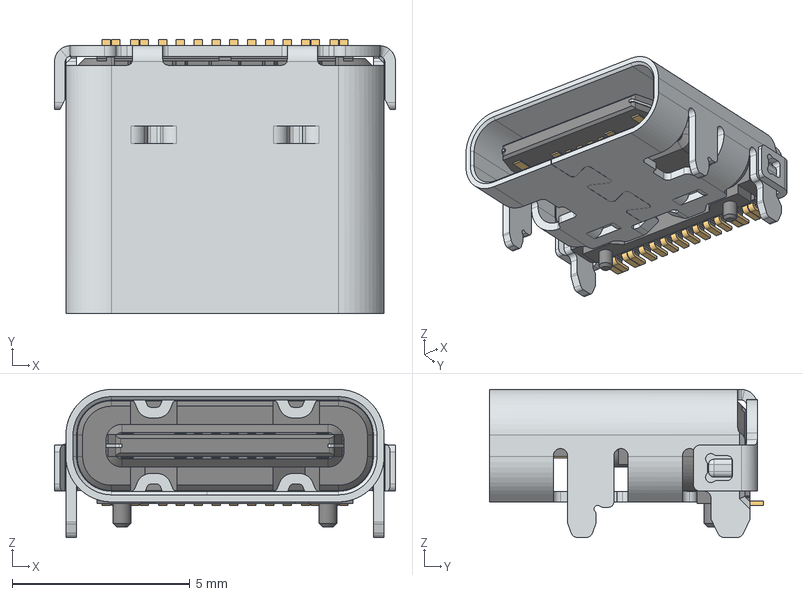
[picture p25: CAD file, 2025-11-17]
HARDWARE/PCB'S/FOC_CONTROLLER_V2/Custom_lib/3D/usb_c_16P.stp
9.58 x 7.71 x 4.16 mm
629722000214_Housing
629722000214_Pin1_Top
629722000214_Pin4_Bottom
629722000214_Pin4_Top x 2
629722000214_Pin1_Bottom
629722000214_Pin3_Bottom
629722000214_Pin3_Top
629722000214_Pin2_Top
629722000214_Pin2_Bottom
629722000214_Pin1_Top_mir
629722000214_Pin1_Bottom_mir
629722000214_Pin2_Top_mir
629722000214_Pin2_Bottom_mir
629722000214_Pin3_Top_mir
629722000214_Pin3_Bottom_mir
629722000214_Pin4_Bottom_mir
629722000214_Shielding2
629722000214_Shielding

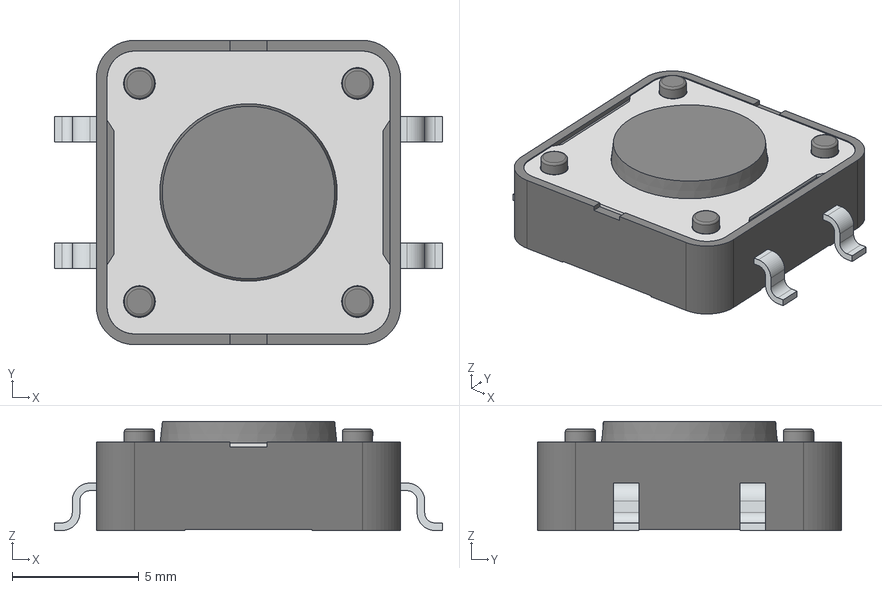
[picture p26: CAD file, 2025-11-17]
HARDWARE/PCB'S/FOC_CONTROLLER_V2/Custom_lib/3D/DeBouton.stp
15.3 x 12.0 x 4.30 mm
Contactplates
Stem
Cover
Contact Plate
Frame
Terminal

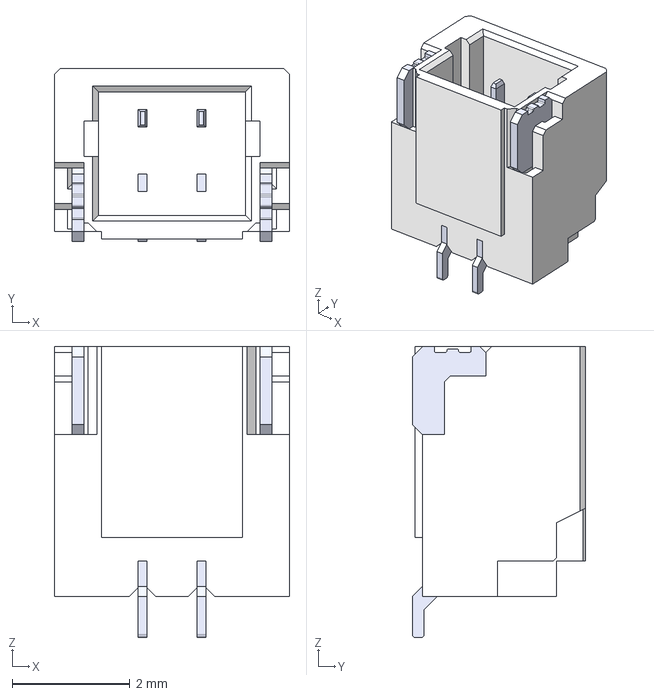
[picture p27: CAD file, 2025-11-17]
HARDWARE/PCB'S/FOC_CONTROLLER_V2/Custom_lib/3D/SM02B-SRSS-TB(LF)(SN).step
4.00 x 2.95 x 4.95 mm

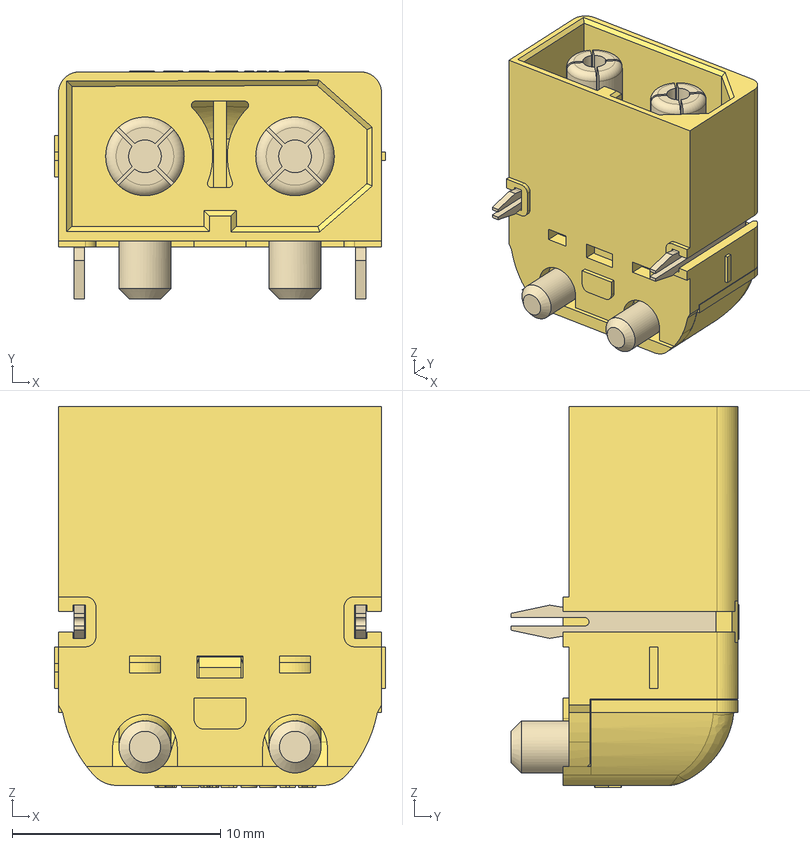
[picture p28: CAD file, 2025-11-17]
HARDWARE/PCB'S/FOC_CONTROLLER_V2/Custom_lib/3D/XT60PW-M.stp
15.9 x 10.9 x 18.3 mm

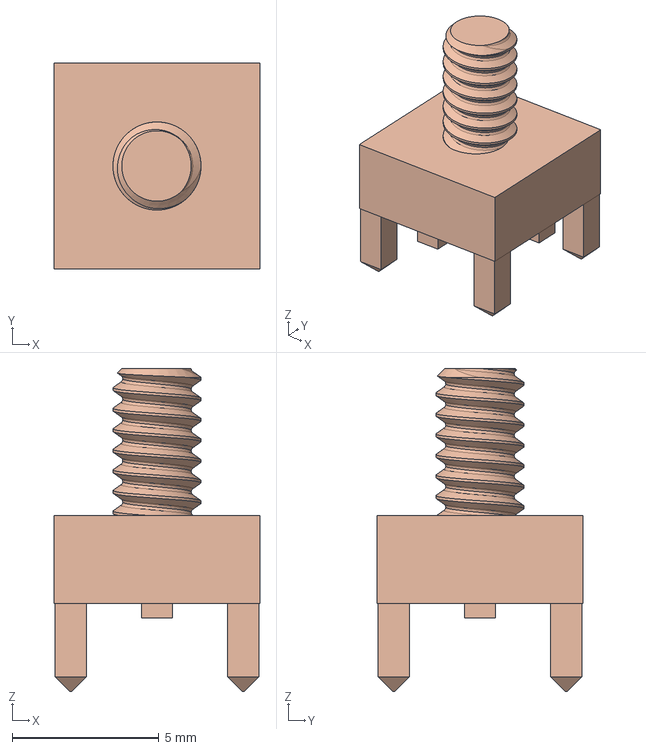
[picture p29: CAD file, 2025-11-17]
HARDWARE/PCB'S/FOC_CONTROLLER_V2/Custom_lib/3D/REDCUBETHT_74651173 (rev1).stp
7.00 x 7.00 x 11.0 mm

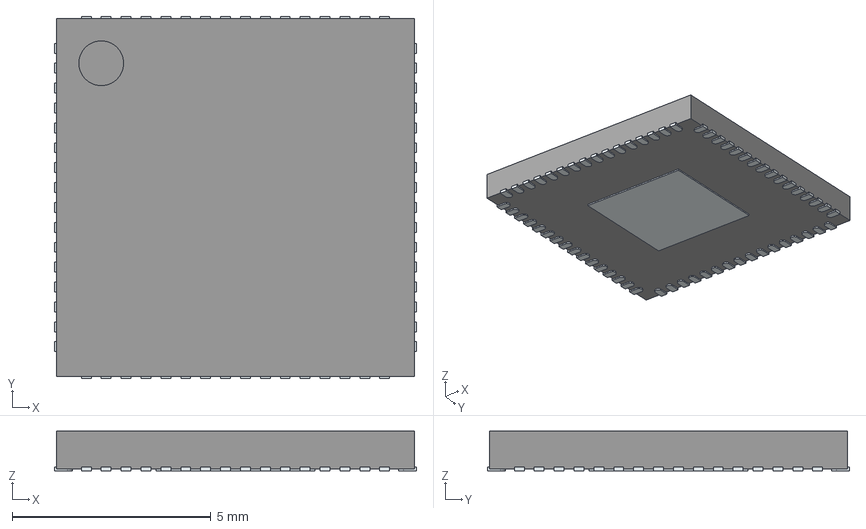
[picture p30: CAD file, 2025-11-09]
HARDWARE/PCB'S/FOC_CONTROLLER_V2/Custom_lib/3D/STSPIN32G4.stp
9.10 x 9.10 x 1.00 mm
ThermalPin
PinsArrayLR
PinsArrayTB

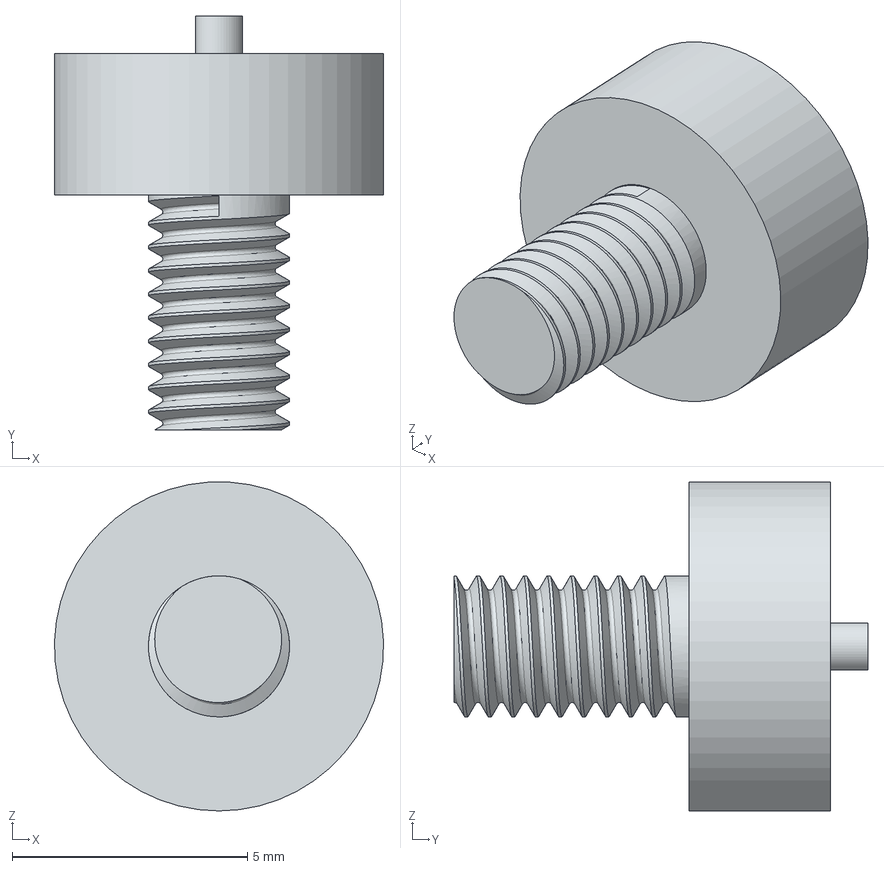
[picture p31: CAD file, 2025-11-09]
HARDWARE/PCB'S/FOC_CONTROLLER_V2/Custom_lib/3D/REDCUBE_7466113 (rev1).stp
7.00 x 8.80 x 6.99 mm

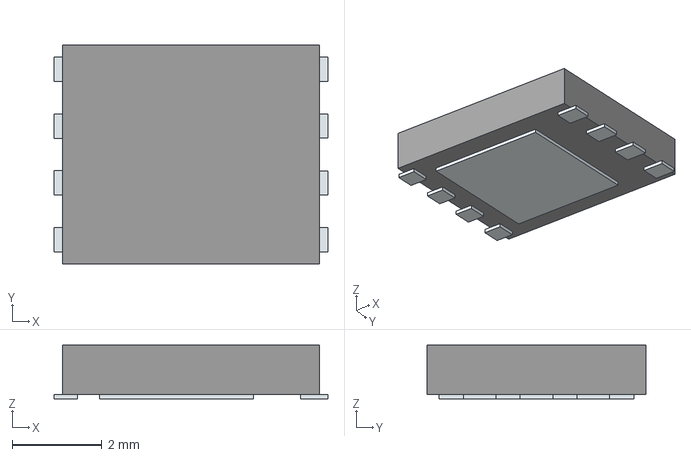
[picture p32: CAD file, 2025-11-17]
HARDWARE/PCB'S/FOC_CONTROLLER_V2/Custom_lib/3D/CSD19534Q5AT.stp
6.12 x 4.90 x 1.20 mm
Pins

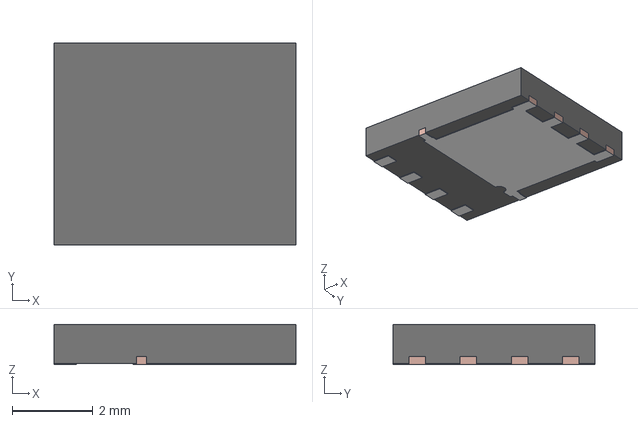
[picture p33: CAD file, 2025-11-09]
HARDWARE/PCB'S/FOC_CONTROLLER_V2/Custom_lib/3D/CSD18510Q5B.stp
6.00 x 5.00 x 1.00 mm
FRAME
MOLD

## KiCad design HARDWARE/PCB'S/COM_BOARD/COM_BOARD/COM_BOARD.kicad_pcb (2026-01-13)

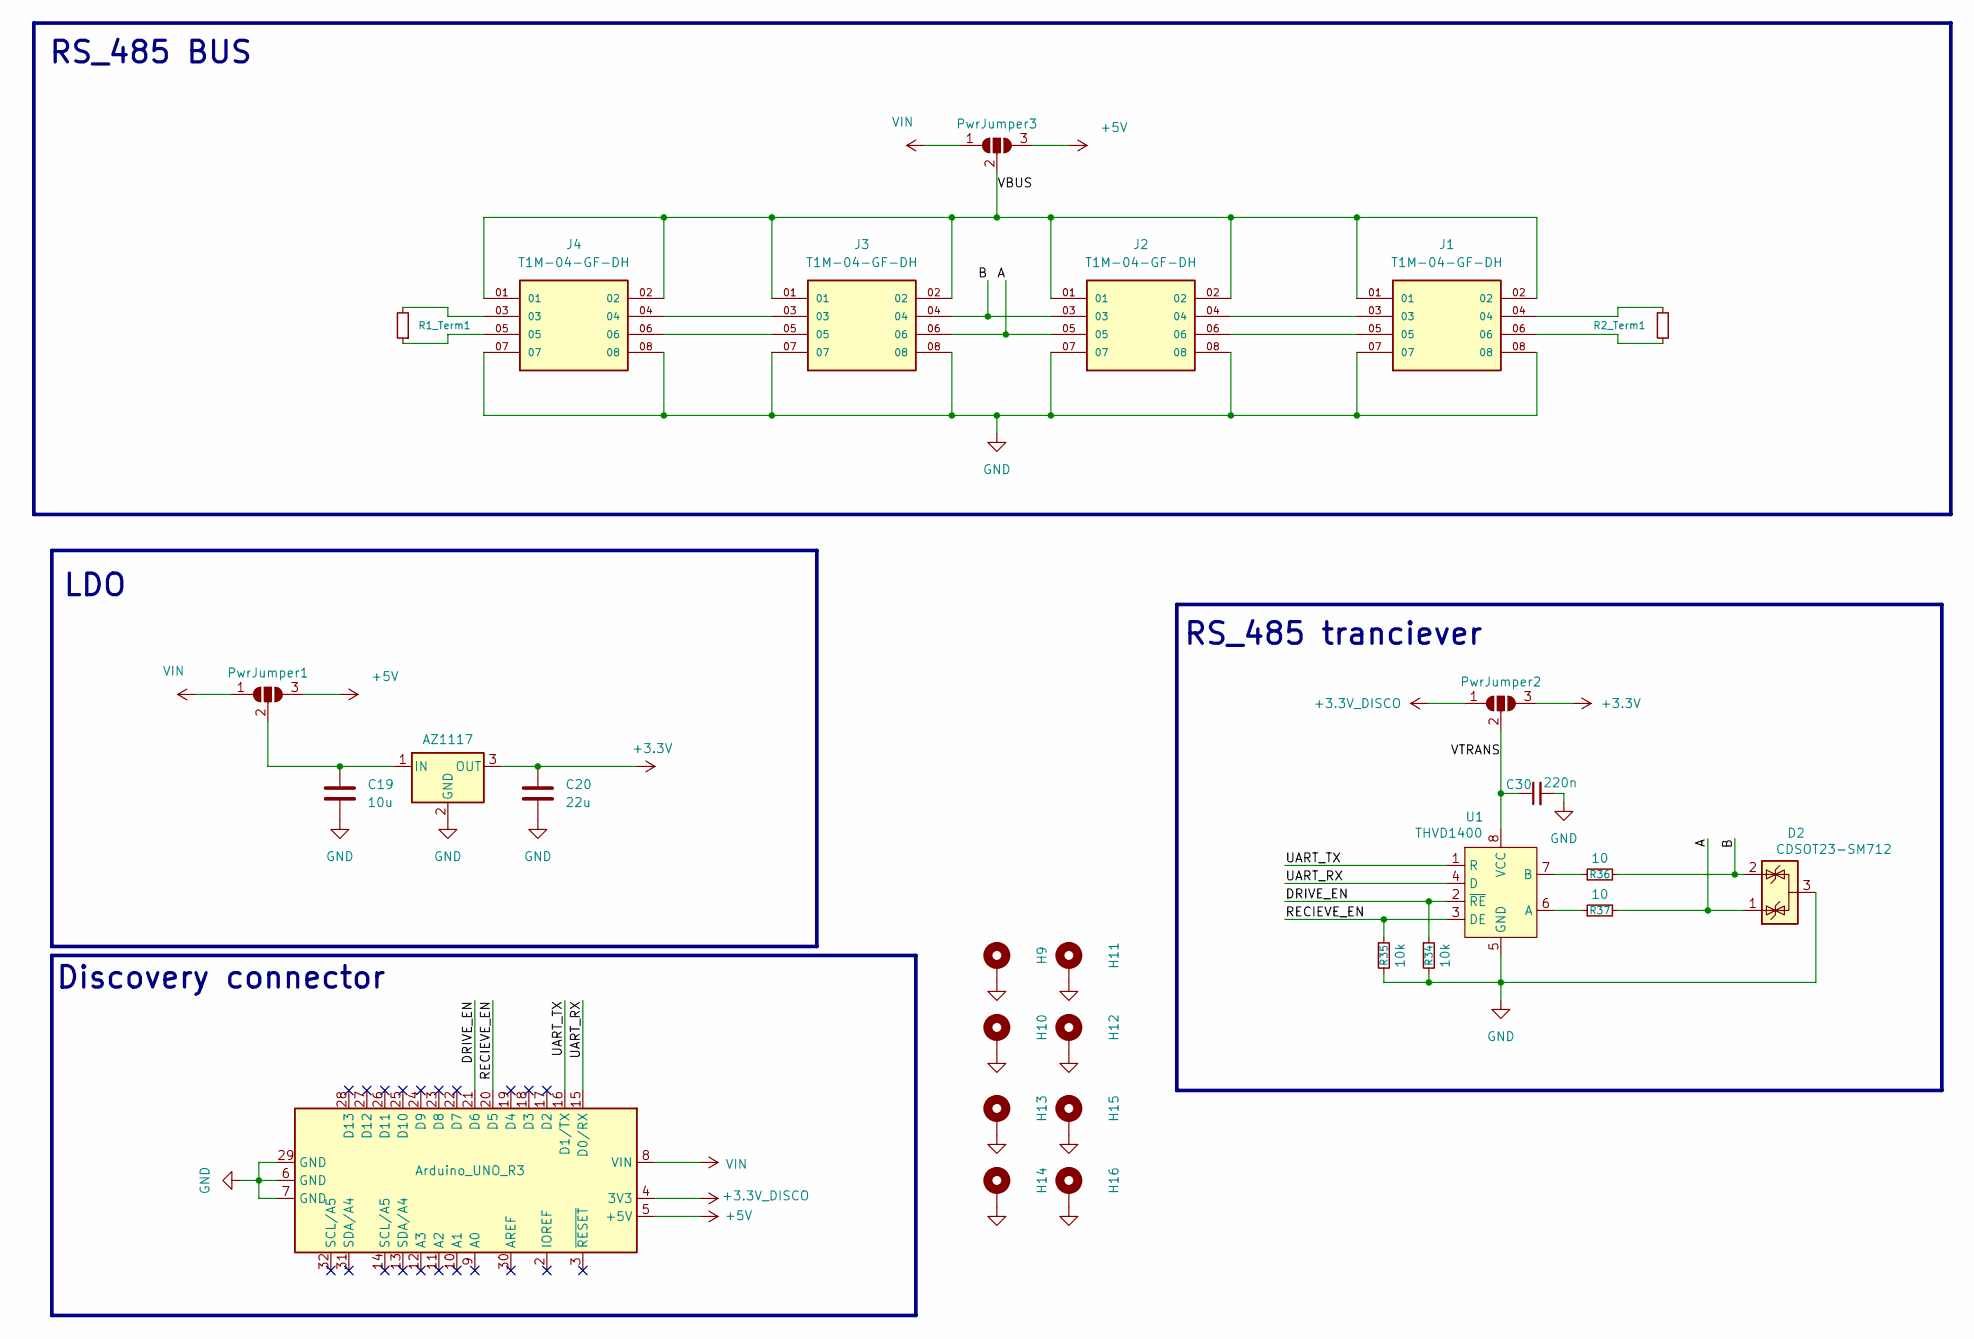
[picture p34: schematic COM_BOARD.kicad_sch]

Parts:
A1: Arduino_UNO_R3
C19: 10u; C_0805_2012Metric_Pad1.18x1.45mm_HandSolder
C20: 22u; C_0805_2012Metric_Pad1.18x1.45mm_HandSolder
C30: 220n; C_0603_1608Metric; MPN 885012207051
D2: CDSOT23-SM712; SOT-23
H9, H10, H11, H12, H13, H14, H15, H16: MountingHole_Pad; MountingHole_3.2mm_M3_Pad_Via
J1, J2, J3, J4: T1M-04-GF-DH; SAMTEC_T1M-04-GF-DH
J10: AZ1117; SOT-223
PwrJumper1, PwrJumper2, PwrJumper3: SolderJumper_3_Open; SolderJumper-3_P1.3mm_Open_RoundedPad1.0x1.5mm_NumberLabels
R1_Term1, R2_Term1: R_Small; R_0603_1608Metric
R34, R35: 10k; R_0603_1608Metric
R36, R37: 10; R_0603_1608Metric
U1: THVD1400; SOIC-8_3.9x4.9mm_P1.27mm

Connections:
+3.3V: C20.1, J10.3 (OUT), PwrJumper2.3 (B)
+3.3V_DISCO: A1.4 (3V3), PwrJumper2.1 (A)
+5V: A1.5 (+5V), PwrJumper1.3 (B), PwrJumper3.3 (B)
/A: D2.1 (K), J2.05, J3.06, R37.2
/B: D2.2 (K), J2.03, J3.04, R36.2
/DRIVE_EN: A1.21 (D6), R34.1, U1.2 (~RE)
/RECIEVE_EN: A1.20 (D5), R35.1, U1.3 (DE)
/UART_RX: A1.15 (D0/RX), U1.4 (D)
/UART_TX: A1.16 (D1/TX), U1.1 (R)
/VBUS: J1.01, J1.02, J2.01, J2.02, J3.01, J3.02, J4.01, J4.02, PwrJumper3.2 (C)
/VTRANS: C30.1, PwrJumper2.2 (C), U1.8 (VCC)
GND: A1.6 (GND), A1.7 (GND), A1.29 (GND), C19.2, C20.2, C30.2, D2.3 (A), H9.1, H10.1, H11.1, H12.1, H13.1, H14.1, H15.1, H16.1, J1.07, J1.08, J2.07, J2.08, J3.07, J3.08, J4.07, J4.08, J10.2 (GND), R34.2, R35.2, U1.5 (GND)
unnamed: J1.03, J2.04
unnamed: J1.04, R2_Term1.1
unnamed: J1.05, J2.06
unnamed: J1.06, R2_Term1.2
unnamed: J3.03, J4.04
unnamed: J3.05, J4.06
unnamed: J4.03, R1_Term1.2
unnamed: J4.05, R1_Term1.1
unnamed: C19.1, J10.1 (IN), PwrJumper1.2 (C)
unnamed: R37.1, U1.6 (A)
unnamed: R36.1, U1.7 (B)
VIN: A1.8 (VIN), PwrJumper1.1 (A), PwrJumper3.1 (A)

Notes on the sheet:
RS_485 tranciever
LDO
Discovery connector
RS_485 BUS

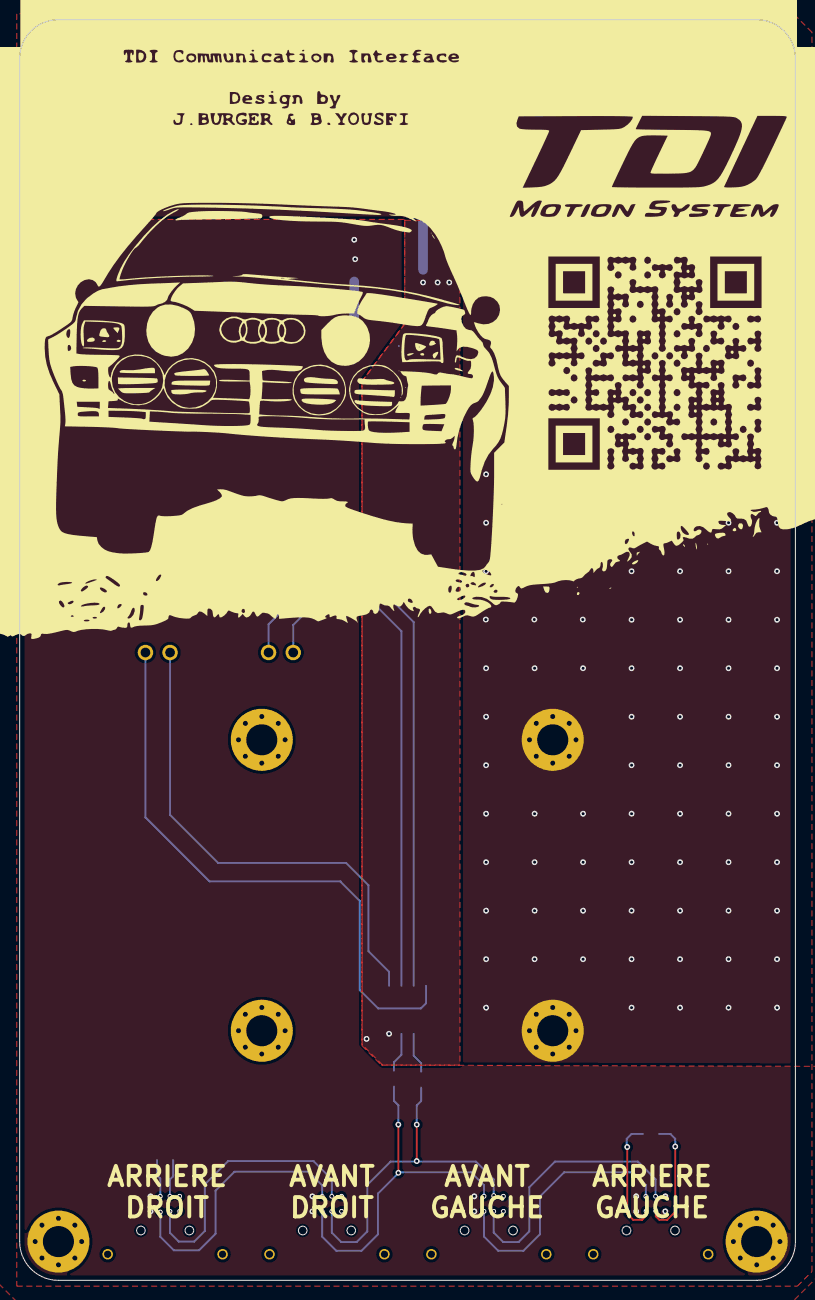
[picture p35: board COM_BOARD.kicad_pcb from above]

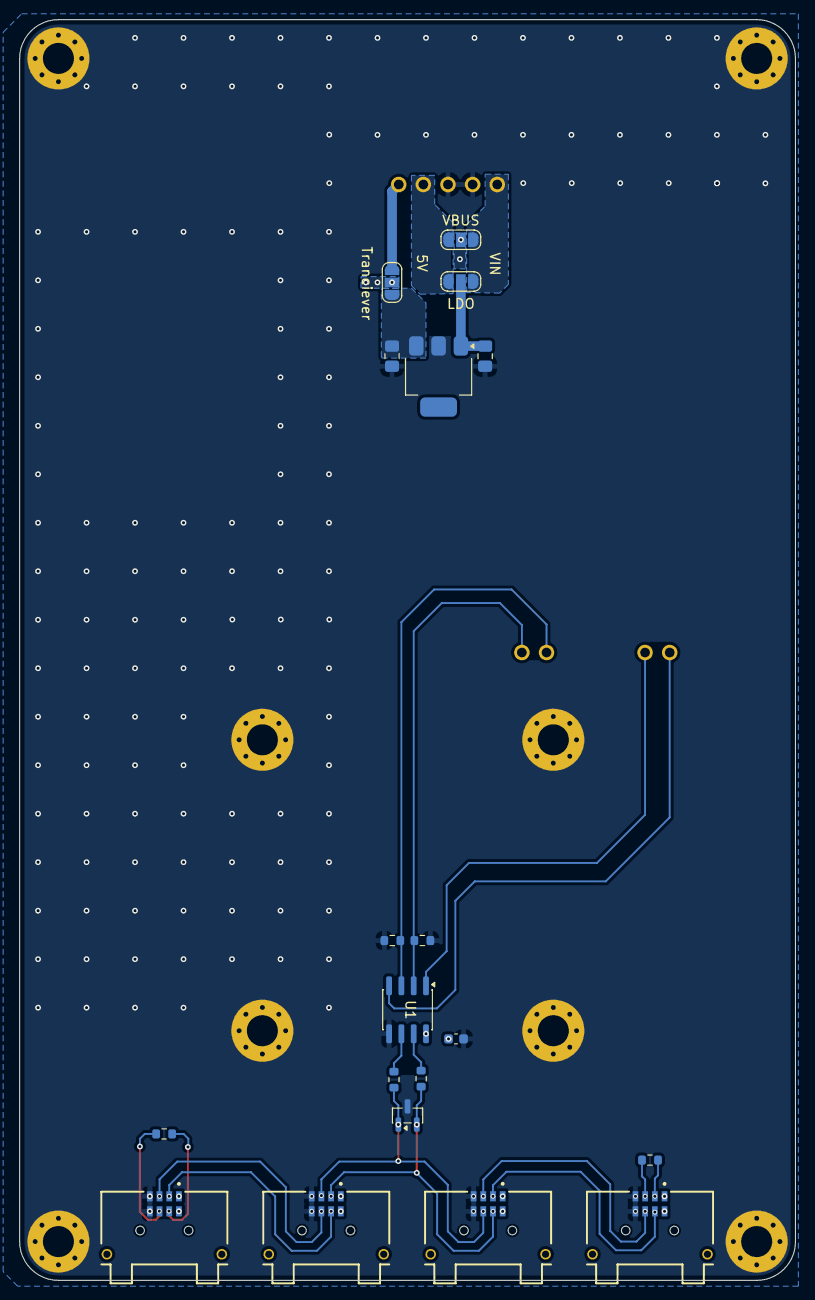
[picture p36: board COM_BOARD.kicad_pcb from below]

Board: 2 copper layers, 80.0 x 130.0 mm, 28 parts (20 on the bottom side), 24 nets.

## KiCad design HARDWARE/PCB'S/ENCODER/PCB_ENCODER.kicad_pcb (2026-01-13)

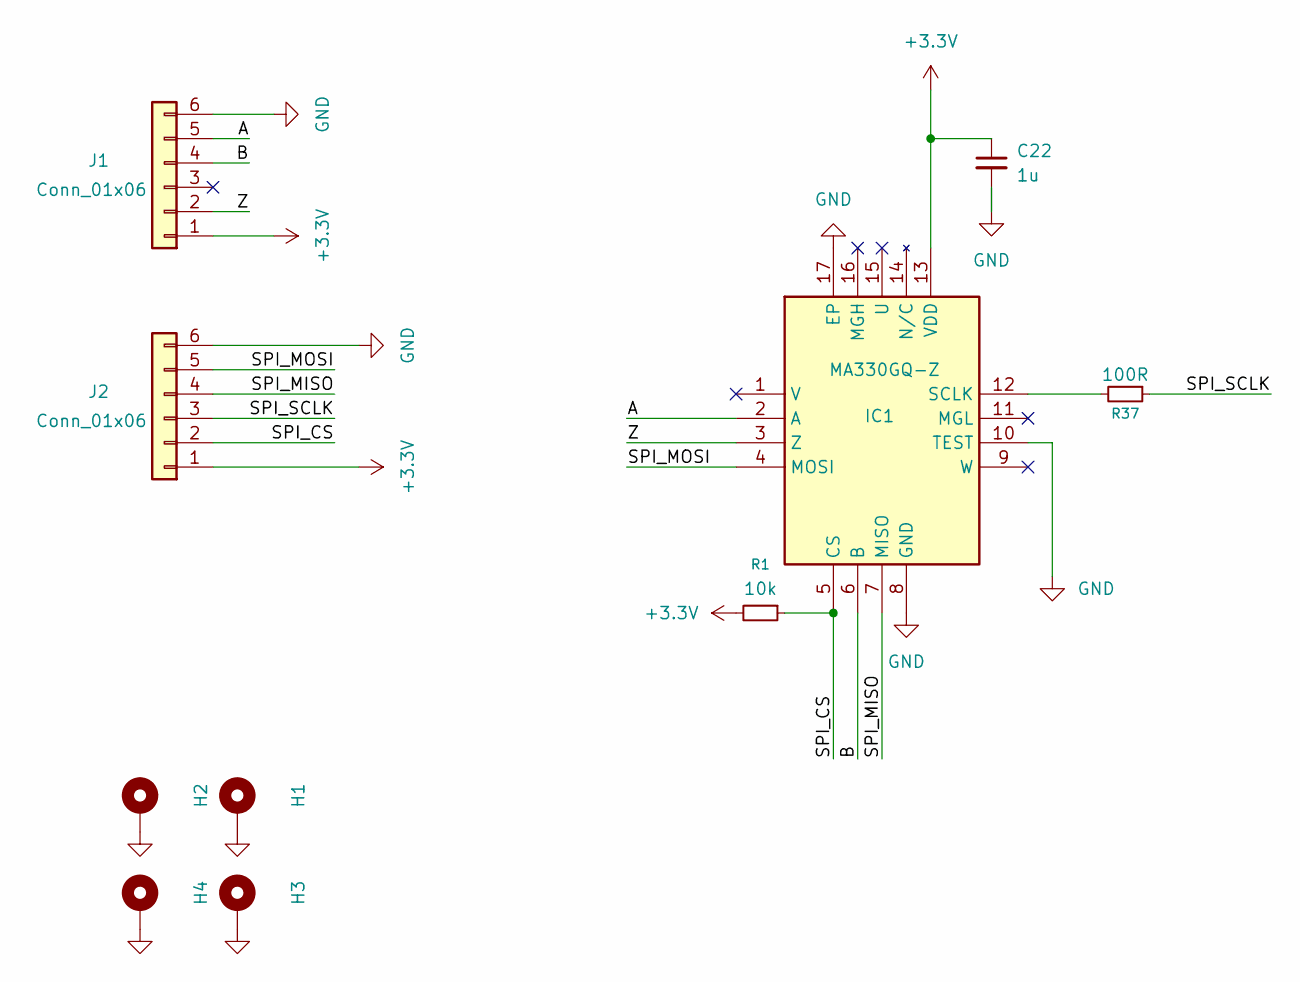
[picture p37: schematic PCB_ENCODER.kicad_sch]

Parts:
C22: 1u; C_0603_1608Metric
H1, H2, H3, H4: MountingHole_Pad; MountingHole_3.2mm_M3_Pad_Via
IC1: MA330GQ-Z; QFN-16-1EP_3x3mm_P0.5mm_EP1.7x1.7mm; Manufacturer_Part_Number MA330GQ-Z; Mouser Part Number 946-MA330GQ-Z
J1, J2: Conn_01x06; JST_GH_SM06B-GHS-TB_1x06-1MP_P1.25mm_Horizontal
R1: 10k; R_0603_1608Metric
R37: 100R; R_0603_1608Metric

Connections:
+3.3V: C22.1, IC1.13 (VDD), J1.1, J2.1, R1.2
/A: IC1.2 (A), J1.5
/B: IC1.6 (B), J1.4
/SPI_CS: IC1.5 (CS), J2.2, R1.1
/SPI_MISO: IC1.7 (MISO), J2.4
/SPI_MOSI: IC1.4 (MOSI), J2.5
/SPI_SCLK: J2.3, R37.1
/Z: IC1.3 (Z), J1.2
GND: C22.2, H1.1, H2.1, H3.1, H4.1, IC1.8 (GND), IC1.10 (TEST), IC1.17 (EP), J1.6, J2.6
unnamed: IC1.12 (SCLK), R37.2

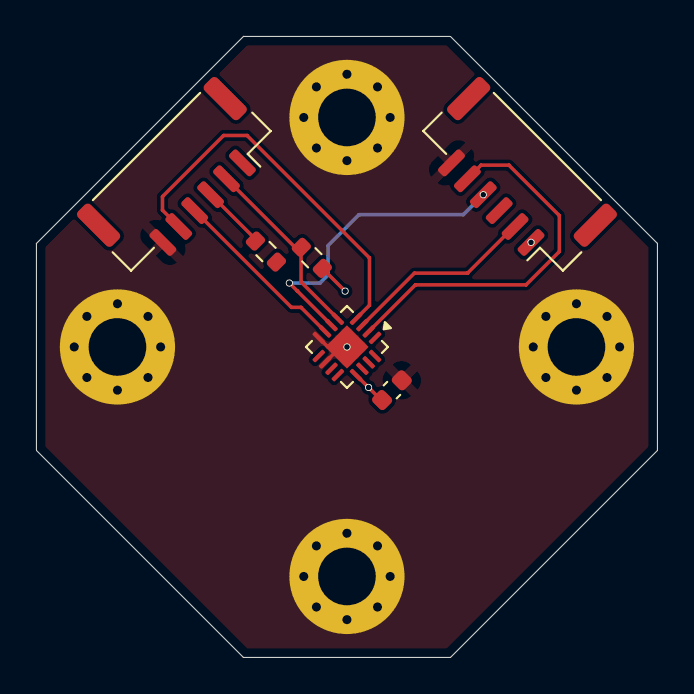
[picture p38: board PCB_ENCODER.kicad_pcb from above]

Board: 2 copper layers, 34.5 x 34.5 mm, 10 parts (0 on the bottom side), 10 nets.

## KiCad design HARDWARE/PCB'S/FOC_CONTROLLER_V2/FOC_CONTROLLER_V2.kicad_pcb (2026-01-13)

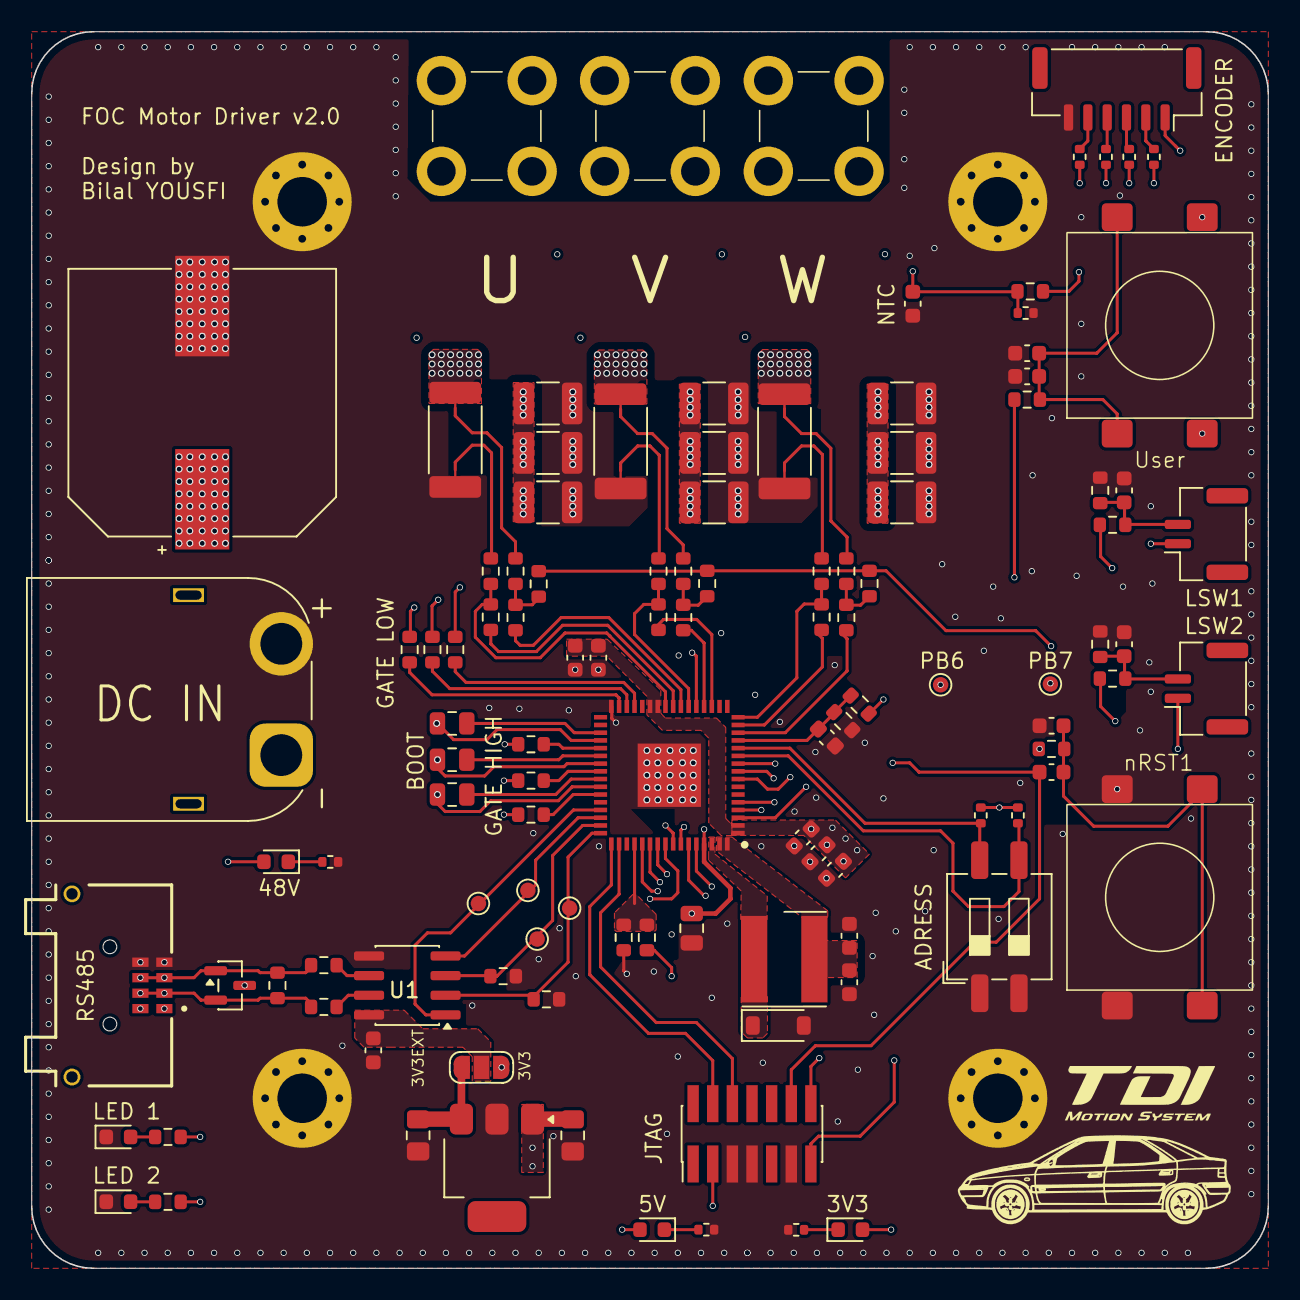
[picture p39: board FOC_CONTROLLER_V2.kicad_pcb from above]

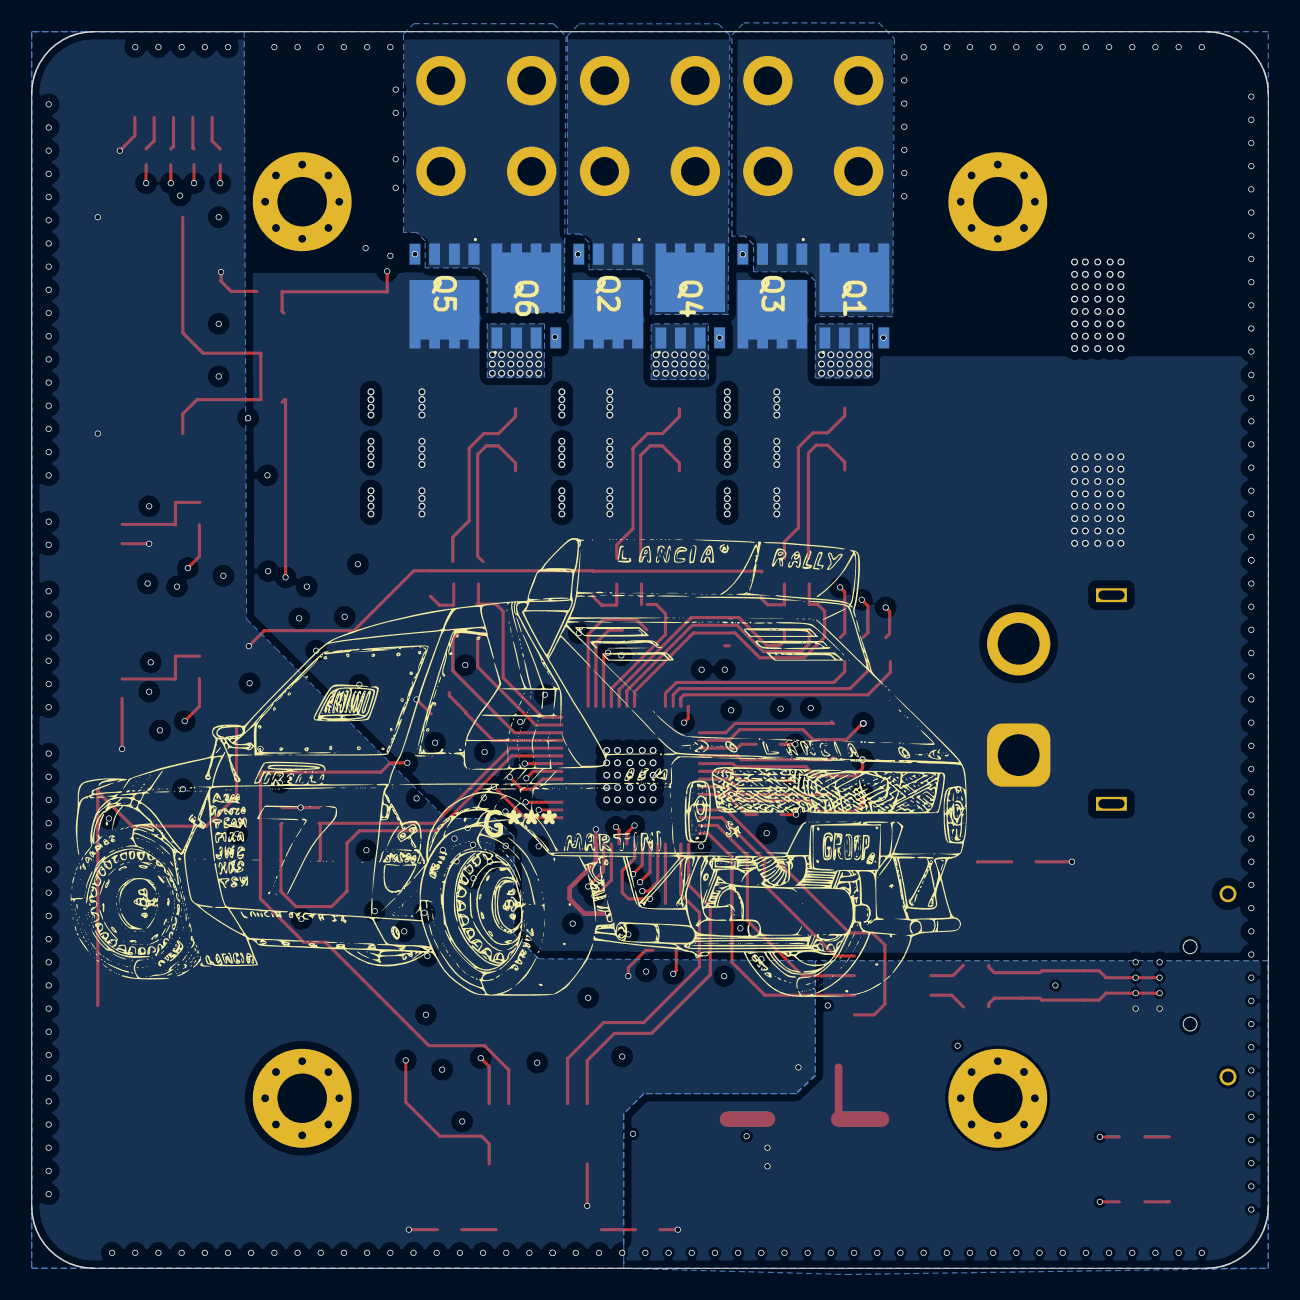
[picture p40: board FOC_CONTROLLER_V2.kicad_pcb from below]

Board: 4 copper layers, 80.0 x 80.0 mm, 124 parts (6 on the bottom side), 89 nets.

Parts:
C1, C3, C5: 1u; C_0805_2012Metric
C2: 220u; CP_Wurth_WCAP-ASLL-D16L17
C4, C6: 220n; C_1210_3225Metric_Pad1.33x2.70mm_HandSolder
C8: 220n; C_0805_2012Metric
C9, C11, C12, C15, C18, C28, C29: 100n; C_0603_1608Metric
C10: 2.2u; C_0603_1608Metric
C13: 10u; C_0603_1608Metric
C14: 1u; C_0603_1608Metric
C16: N.M.; C_0603_1608Metric
C17, C24: 33n; C_0603_1608Metric
C19: 10u; C_0805_2012Metric_Pad1.18x1.45mm_HandSolder
C20: 22u; C_0805_2012Metric_Pad1.18x1.45mm_HandSolder
C21, C22, C26, C27, C31, C32, C33: N.M.; C_1210_3225Metric_Pad1.33x2.70mm_HandSolder
C30: 220n; C_0603_1608Metric
D1, D3, D5, D8, D9: LED; LED_0603_1608Metric
D2: CDSOT23-SM712; SOT-23
D4: STPS0560Z; D_SOD-123
H1, H2, H3, H4: MountingHole_Pad; MountingHole_3.2mm_M3_Pad_Via
IC1: STSPIN32G4; QFN50P900X900X100-65N-D
J1: DC IN; AMASS_XT60PW-M_1x02_P7.20mm_Horizontal
J2, J3, J4: Conn_01x01; REDCUBETHT_74651173R
J6: JTAG; PinHeader_2x07_P1.27mm_Vertical_SMD
J10: AZ1117; SOT-223
J11: T1M-04-GF-DH; SAMTEC_T1M-04-GF-DH
J12: Conn_01x06; JST_GH_SM06B-GHS-TB_1x06-1MP_P1.25mm_Horizontal
L1: 15u; L_Wurth_WE-MXGI-5030
LSW1, LSW2: Conn_SW_2; JST_GH_SM02B-GHS-TB_1x02-1MP_P1.25mm_Horizontal
NTC1: 10K; R_0603_1608Metric
PwrJumper1: SolderJumper_3_Open; SolderJumper-3_P1.3mm_Open_RoundedPad1.0x1.5mm_NumberLabels
Q1, Q4, Q6: CSD18543Q3A; CSD18540Q5BT
Q2, Q3, Q5: CSD19534Q5A; CSD18540Q5BT
R1, R3, R4, R5, R6, R7: 100; R_0603_1608Metric
R2: 22k; R_0603_1608Metric
R8, R49, R51: 100k; R_0603_1608Metric
R9: 200; C_0603_1608Metric
R10, R34, R35: 10k; R_0603_1608Metric
R11, R48: 330; R_0603_1608Metric
R12: 100k; C_0603_1608Metric
R13, R16, R18, R19, R23, R24: 1.5k; R_0603_1608Metric
R14, R15, R20, R21, R25, R26: 30K; R_0603_1608Metric
R17, R22, R27: 15k; R_0603_1608Metric
R28: 72.3k; R_0603_1608Metric
R29: 3.01k; R_0603_1608Metric
R30, R50, R52: 200; R_0603_1608Metric
R31, R32, R33: R_Shunt; R_2512_6332Metric_Pad1.40x3.35mm_HandSolder
R36, R37, R53: 10; R_0603_1608Metric
R38: 2k5; R_0402_1005Metric
R39: 1k5; R_0402_1005Metric
R40: 12k; R_0402_1005Metric
R41, R42, R43, R44: 200; R_0402_1005Metric
R45: 4.7k; R_0402_1005Metric
R46, R47: 10k; R_0402_1005Metric
SW3: SW_DIP_x02; SW_DIP_SPSTx02_Slide_6.7x6.64mm_W8.61mm_P2.54mm_LowProfile
TP1, TP2, TP3, TP4: 3V3; TestPoint_Pad_D1.0mm
TP14, TP15: 5V; TestPoint_Pad_D1.0mm
U1: THVD1400; SOIC-8_3.9x4.9mm_P1.27mm
User: SW_MEC_5G; DeBouton
nRST1: SW_MEC_5G; DeBouton

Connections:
+3,3V_EXT: C20.1, J10.3 (OUT), PwrJumper1.3 (B)
+3.3V: C10.1, C11.1, C12.1, C14.1, C15.1, D9.2 (A), IC1.1 (REG3V3/VDD), IC1.2 (VBAT), IC1.26 (VREF+), IC1.27 (VDDA), J6.3 (VCC), J12.1, LSW1.1, LSW2.1, NTC1.1, PwrJumper1.1 (A), R2.2, R8.1, R14.2, R20.2, R25.2, R46.2, R47.2, User.3 (B), User.4 (B)
+5V: C19.1, D8.2 (A), J10.1 (IN), J11.01, J11.02
+48V: C2.1, C4.2, C6.2, C8.1, C21.2, C22.2, C26.2, C27.2, C31.2, C32.2, C33.2, D5.2 (A), IC1.61 (VM), J1.1, Q2.5 (D), Q3.5 (D), Q5.5 (D), R28.1
/A: D2.1 (K), J11.05, J11.06, R37.2, R53.1
/ADD_SEL_0: IC1.12 (PC3), R47.1, SW3.4
/ADD_SEL_1: IC1.11 (PC2), R46.1, SW3.3
/Ampli_1/VSHUNTXN: R16.1, R31.2
/Ampli_1/VSHUNTXP: R18.1, R31.3
/Ampli_2/VSHUNTXN: R13.1, R32.2
/Ampli_2/VSHUNTXP: R19.1, R32.3
/Ampli_3/VSHUNTXN: R23.1, R33.2
/Ampli_3/VSHUNTXP: R24.1, R33.3
/B: D2.2 (K), J11.03, J11.04, R36.2, R53.2
/BOOT1: C1.1, IC1.41 (BOOT1)
/BOOT2: C3.1, IC1.38 (BOOT2)
/BOOT3: C5.1, IC1.35 (BOOT3)
/Conn_SW_1: C28.2, LSW1.2, R49.1, R50.1
/Conn_SW_2: C29.2, LSW2.2, R51.1, R52.1
/DRIVE_EN: IC1.48 (PA12), R34.1, TP2.1, U1.2 (~RE)
/GHS1: IC1.43 (GHS1), R4.1
/GHS2: IC1.40 (GHS2), R1.1
/GHS3: IC1.37 (GHS3), R6.1
/GLS1: IC1.29 (GLS1), R3.1
/GLS2: IC1.30 (GLS2), R5.1
/GLS3: IC1.31 (GLS3), R7.1
/L_SW_1: IC1.60 (PB9), R50.2
/L_SW_2: IC1.59 (PB8), R52.2
/NRST: IC1.8 (PG10), J6.12 (~RST), R9.2
/NTC: C24.2, IC1.21 (PC4), NTC1.2, R45.1
/OPN1: IC1.25 (PB2), R16.2, R17.1
/OPN2: IC1.22 (PC5), R13.2, R22.1
/OPN3: IC1.16 (PA3), R23.2, R27.1
/OPO1: IC1.24 (PB1), R17.2
/OPO2: IC1.19 (PA6), R22.2
/OPO3: IC1.15 (PA2), R27.2
/OPP1: IC1.23 (PB0), R15.1
/OPP2: IC1.20 (PA7), R21.1
/OPP3: IC1.14 (PA1), R26.1
/OUT1: C1.2, IC1.42 (OUT1), J2.1, Q1.5 (D), Q3.1 (S), Q3.2 (S), Q3.3 (S)
/OUT2: C3.2, IC1.39 (OUT2), J3.1, Q2.1 (S), Q2.2 (S), Q2.3 (S), Q4.5 (D)
/OUT3: C5.2, IC1.36 (OUT3), J4.1, Q5.1 (S), Q5.2 (S), Q5.3 (S), Q6.5 (D)
/PB6: IC1.57 (PB6), TP15.1
/PB7: IC1.58 (PB7), TP14.1
/RECIEVE_EN: IC1.47 (PA11), R35.1, TP1.1, U1.3 (DE)
/SPI_CS: J12.2, R44.2
/SPI_MISO: J12.4, R42.2
/SPI_MOSI: J12.5, R41.2
/SPI_SCLK: J12.3, R43.2
/SW: D4.1 (K), IC1.62 (SW), L1.1
/SWCLK: IC1.50 (PA14), J6.6 (JCLK/SWCLK)
/SWDIO: IC1.49 (PA13), J6.4 (JTMS/SWDIO)
/UART_RX: IC1.46 (PA10), TP3.1, U1.4 (D)
/UART_TX: IC1.45 (PA9), TP4.1, U1.1 (R)
/User: IC1.3 (PC13), R30.2
/VCP_RX: IC1.10 (PC1), J6.13 (VCP_RX)
/VCP_TX: IC1.9 (PC0), J6.14 (VCP_TX)
GND: C2.2, C4.1, C6.1, C8.2, C9.2, C10.2, C11.2, C12.2, C13.2, C14.2, C15.2, C16.2, C17.2, C18.1, C19.2, C20.2, C21.1, C22.1, C24.1, C26.1, C27.1, C28.1, C29.1, C30.2, C31.1, C32.1, C33.1, D1.1 (K), D2.3 (A), D3.1 (K), D4.2 (A), H1.1, H2.1, H3.1, H4.1, IC1.32 (PGND), IC1.65 (VSS), J1.2, J6.5 (GND), J6.7 (GND), J6.11 (GNDDetect), J10.2 (GND), J11.07, J11.08, J12.6, R10.1, R12.2, R29.2, R31.1, R32.1, R33.1, R34.2, R35.2, R38.2, R39.2, R40.2, R45.2, R49.2, R51.2, SW3.1, SW3.2, U1.5 (GND), nRST1.1 (A), nRST1.2 (A)
unnamed: C9.1, R8.2, R9.1, nRST1.3 (B), nRST1.4 (B)
unnamed: C18.2, R12.1, R30.1, User.1 (A), User.2 (A)
unnamed: D1.2 (A), R11.2
unnamed: D3.2 (A), R48.2
unnamed: D5.1 (K), R40.1
unnamed: D8.1 (K), R38.1
unnamed: D9.1 (K), R39.1
unnamed: C17.1, IC1.13 (PA0), R28.2, R29.1
unnamed: IC1.54 (PB3), R43.1
unnamed: IC1.55 (PB4), R42.1
unnamed: IC1.56 (PB5), R41.1
unnamed: IC1.4 (PC14), R11.1
unnamed: IC1.5 (PC15), R48.1
unnamed: IC1.53 (PD2), R44.1
unnamed: C13.1, C16.1, IC1.63 (VCC), IC1.64 (REGIN), L1.2
unnamed: IC1.52 (SCREF), R2.1, R10.2
unnamed: C30.1, PwrJumper1.2 (C), U1.8 (VCC)
unnamed: Q1.4 (G), R3.2
unnamed: Q1.1 (S), Q1.2 (S), Q1.3 (S), R31.4
unnamed: Q2.4 (G), R1.2
unnamed: Q3.4 (G), R4.2
unnamed: Q4.4 (G), R5.2
unnamed: Q4.1 (S), Q4.2 (S), Q4.3 (S), R32.4
unnamed: Q5.4 (G), R6.2
unnamed: Q6.4 (G), R7.2
unnamed: Q6.1 (S), Q6.2 (S), Q6.3 (S), R33.4
unnamed: R14.1, R15.2, R18.2
unnamed: R19.2, R20.1, R21.2
unnamed: R24.2, R25.1, R26.2
unnamed: R37.1, U1.6 (A)
unnamed: R36.1, U1.7 (B)

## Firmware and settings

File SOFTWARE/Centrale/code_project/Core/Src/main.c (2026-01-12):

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
/* Includes ------------------------------------------------------------------*/
#include "main.h"
#include "cmsis_os.h"
#include "fatfs.h"
#include "libjpeg.h"
#include "app_touchgfx.h"

/* USER CODE BEGIN Includes */
#include "mutexRTOSDOFs.h"
#include "stdlib.h"
#include "string.h"
#include "stm32f7xx.h"
/* USER CODE END Includes */

/* USER CODE BEGIN PD */

#define REFRESH_COUNT        1835

#define SDRAM_TIMEOUT                            ((uint32_t)0xFFFF)
#define SDRAM_MODEREG_BURST_LENGTH_1             ((uint16_t)0x0000)
#define SDRAM_MODEREG_BURST_LENGTH_2             ((uint16_t)0x0001)
#define SDRAM_MODEREG_BURST_LENGTH_4             ((uint16_t)0x0002)
#define SDRAM_MODEREG_BURST_LENGTH_8             ((uint16_t)0x0004)
#define SDRAM_MODEREG_BURST_TYPE_SEQUENTIAL      ((uint16_t)0x0000)
#define SDRAM_MODEREG_BURST_TYPE_INTERLEAVED     ((uint16_t)0x0008)
#define SDRAM_MODEREG_CAS_LATENCY_2              ((uint16_t)0x0020)
#define SDRAM_MODEREG_CAS_LATENCY_3              ((uint16_t)0x0030)
#define SDRAM_MODEREG_OPERATING_MODE_STANDARD    ((uint16_t)0x0000)
#define SDRAM_MODEREG_WRITEBURST_MODE_PROGRAMMED ((uint16_t)0x0000)
#define SDRAM_MODEREG_WRITEBURST_MODE_SINGLE     ((uint16_t)0x0200)

#define FLASH_READ_JEDEC_ID				0x9F
#define FLASH_FAST_READ_QUAD_IO		 	0xEB
#define FLASH_REVC03_MANUFACTURER_ID	0xEF
#define FLASH_N25Q128A_DUMMY_CYCLES		0x0A
#define FLASH_W25Q128J_DUMMY_CYCLES		0x06

/* USER CODE END PD */


CRC_HandleTypeDef hcrc;

DMA2D_HandleTypeDef hdma2d;

I2C_HandleTypeDef hi2c3;

LTDC_HandleTypeDef hltdc;

QSPI_HandleTypeDef hqspi;

SD_HandleTypeDef hsd1;

UART_HandleTypeDef huart7;
UART_HandleTypeDef huart1;
DMA_HandleTypeDef hdma_uart7_rx;

SDRAM_HandleTypeDef hsdram1;

/* Definitions for defaultTask */
osThreadId_t defaultTaskHandle;
const osThreadAttr_t defaultTask_attributes = {
  .name = "defaultTask",
  .stack_size = 128 * 4,
  .priority = (osPriority_t) osPriorityNormal,
};
/* Definitions for TouchGFXTask */
osThreadId_t TouchGFXTaskHandle;
const osThreadAttr_t TouchGFXTask_attributes = {
  .name = "TouchGFXTask",
  .stack_size = 4096 * 4,
  .priority = (osPriority_t) osPriorityNormal,
};
/* Definitions for videoTask */
osThreadId_t videoTaskHandle;
const osThreadAttr_t videoTask_attributes = {
  .name = "videoTask",
  .stack_size = 1000 * 4,
  .priority = (osPriority_t) osPriorityLow,
};
/* USER CODE BEGIN PV */
static FMC_SDRAM_CommandTypeDef Command;

#define START_BYTE 0x42
#define SEP_BYTE   0x21
#define END_BYTE   0x45
#define RX_BUF_SIZE 64

uint8_t dmaRxBuffer[RX_BUF_SIZE];
uint8_t frameBuffer[RX_BUF_SIZE];
uint16_t frameLength = 0;


osThreadId_t uartTaskHandle;
const osThreadAttr_t uartTask_attributes = {
		.name = "uartTask",
		.stack_size = 512 * 4,
		.priority = (osPriority_t) osPriorityLow,
};

uint8_t rxData;
/* USER CODE END PV */

void SystemClock_Config(void);
static void MPU_Config(void);
static void MX_GPIO_Init(void);
static void MX_DMA_Init(void);
static void MX_CRC_Init(void);
static void MX_DMA2D_Init(void);
static void MX_FMC_Init(void);
static void MX_I2C3_Init(void);
static void MX_LTDC_Init(void);
static void MX_QUADSPI_Init(void);
static void MX_USART1_UART_Init(void);
static void MX_SDMMC1_SD_Init(void);
static void MX_UART7_Init(void);
void StartDefaultTask(void *argument);
extern void TouchGFX_Task(void *argument);
extern void videoTaskFunc(void *argument);

/* USER CODE BEGIN PFP */
void GetManufacturerId (uint8_t *manufacturer_id);
void EnableMemoryMappedMode(uint8_t manufacturer_id);  

void StartUartTask(void *argument);

/* USER CODE END PFP */

/* USER CODE BEGIN 0 */
uint8_t rx_buffer[8];
volatile uint8_t rx_complete = 0;

/* USER CODE END 0 */

/**
  * @brief  The application entry point.
  * @retval int
  */
int main(void)
{

  /* MPU Configuration--------------------------------------------------------*/
  MPU_Config();

  /* Enable the CPU Cache */

  /* Enable I-Cache---------------------------------------------------------*/
  SCB_EnableICache();

  /* Enable D-Cache---------------------------------------------------------*/
  SCB_EnableDCache();

  /* MCU Configuration--------------------------------------------------------*/

  /* Reset of all peripherals, Initializes the Flash interface and the Systick. */
  HAL_Init();

  /* Configure the system clock */
  SystemClock_Config();

  /* Initialize all configured peripherals */
  MX_GPIO_Init();
  MX_DMA_Init();
  MX_CRC_Init();
  MX_DMA2D_Init();
  MX_FMC_Init();
  MX_I2C3_Init();
  MX_LTDC_Init();
  MX_QUADSPI_Init();
  MX_LIBJPEG_Init();
  MX_USART1_UART_Init();
  MX_SDMMC1_SD_Init();
  MX_FATFS_Init();
  MX_UART7_Init();
  MX_TouchGFX_Init();
  /* Call PreOsInit function */
  MX_TouchGFX_PreOSInit();
  /* Init scheduler */
  osKernelInitialize();

  /* USER CODE BEGIN RTOS_MUTEX */
  /* create mutexes, ... */
  if (g_axesMutex == NULL)
  {
	  InitAxesMutex();
  }


  /* USER CODE END RTOS_MUTEX */

  /* USER CODE BEGIN RTOS_SEMAPHORES */
  /* add semaphores, ... */
  /* USER CODE END RTOS_SEMAPHORES */

  /* USER CODE BEGIN RTOS_TIMERS */
  /* start timers, add new ones, ... */
  /* USER CODE END RTOS_TIMERS */

  /* USER CODE BEGIN RTOS_QUEUES */
  /* add queues, ... */
//  uartQueueHandle = osMessageQueueNew(4, sizeof(uint16_t), NULL);

  /* USER CODE END RTOS_QUEUES */

  /* Create the thread(s) */
  /* creation of defaultTask */
  defaultTaskHandle = osThreadNew(StartDefaultTask, NULL, &defaultTask_attributes);

  /* creation of TouchGFXTask */
  TouchGFXTaskHandle = osThreadNew(TouchGFX_Task, NULL, &TouchGFXTask_attributes);

  /* creation of videoTask */
  videoTaskHandle = osThreadNew(videoTaskFunc, NULL, &videoTask_attributes);

  /* USER CODE BEGIN RTOS_THREADS */
  /* add threads, ... */
  /* creation of uartTask */
  uartTaskHandle = osThreadNew(StartUartTask, NULL, &uartTask_attributes);
  /* USER CODE END RTOS_THREADS */

  /* USER CODE BEGIN RTOS_EVENTS */
  /* add events, ... */
  /* USER CODE END RTOS_EVENTS */

  /* Start scheduler */
  osKernelStart();

  /* We should never get here as control is now taken by the scheduler */

  /* Infinite loop */
  /* USER CODE BEGIN WHILE */
  while (1)
  {
    /* USER CODE END WHILE */

    /* USER CODE BEGIN 3 */
  }
  /* USER CODE END 3 */
}

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
/* USER CODE BEGIN 4 */

// Read manufacturer ID of external QSPI flash
void GetManufacturerId (uint8_t *manufacturer_id)
{
  QSPI_CommandTypeDef s_command_id;

  /* Initialize the read flag status register command */
  s_command_id.InstructionMode   = QSPI_INSTRUCTION_1_LINE;
  s_command_id.Instruction       = FLASH_READ_JEDEC_ID;
  s_command_id.AddressMode       = QSPI_ADDRESS_NONE;
  s_command_id.AlternateByteMode = QSPI_ALTERNATE_BYTES_NONE;
  s_command_id.DataMode          = QSPI_DATA_1_LINE;
  s_command_id.DummyCycles       = 0;
  s_command_id.NbData            = 1;
  s_command_id.DdrMode           = QSPI_DDR_MODE_DISABLE;
  s_command_id.DdrHoldHalfCycle  = QSPI_DDR_HHC_ANALOG_DELAY;
  s_command_id.SIOOMode          = QSPI_SIOO_INST_EVERY_CMD;

  /* Configure the command */
  if (HAL_QSPI_Command(&hqspi, &s_command_id, HAL_QPSI_TIMEOUT_DEFAULT_VALUE) != HAL_OK)
  {
	  Error_Handler();
  }

  /* Reception of the data */
  if (HAL_QSPI_Receive(&hqspi, manufacturer_id, HAL_QPSI_TIMEOUT_DEFAULT_VALUE) != HAL_OK)
  {
	  Error_Handler();
  }
}

// Enable memory mapped mode for external QSPI flash
void EnableMemoryMappedMode(uint8_t manufacturer_id)  
{
  QSPI_CommandTypeDef      s_command;
  QSPI_MemoryMappedTypeDef s_mem_mapped_cfg;

  /* Configure the command for the read instruction */
  s_command.InstructionMode   = QSPI_INSTRUCTION_1_LINE;
  s_command.Instruction       = FLASH_FAST_READ_QUAD_IO;
  s_command.AddressMode       = QSPI_ADDRESS_4_LINES;
  s_command.AddressSize       = QSPI_ADDRESS_24_BITS;
  s_command.AlternateByteMode = QSPI_ALTERNATE_BYTES_NONE;
  s_command.DataMode          = QSPI_DATA_4_LINES;
  
  // Set dummy cycles according to manufacturer ID
  s_command.DummyCycles       = manufacturer_id == FLASH_REVC03_MANUFACTURER_ID ? FLASH_W25Q128J_DUMMY_CYCLES : FLASH_N25Q128A_DUMMY_CYCLES;

  s_command.DdrMode           = QSPI_DDR_MODE_DISABLE;
  s_command.DdrHoldHalfCycle  = QSPI_DDR_HHC_ANALOG_DELAY;
  s_command.SIOOMode          = QSPI_SIOO_INST_EVERY_CMD;
  
  /* Configure the memory mapped mode */
  s_mem_mapped_cfg.TimeOutActivation = QSPI_TIMEOUT_COUNTER_DISABLE;
  s_mem_mapped_cfg.TimeOutPeriod     = 0;
  
  if (HAL_QSPI_MemoryMapped(&hqspi, &s_command, &s_mem_mapped_cfg) != HAL_OK)
  {
    Error_Handler();
  }
}


void StartUartTask(void *argument)
{
//	char *msg = "USART2 ready. Type something:\r\n";
//	HAL_UART_Transmit(&huart1, (uint8_t*)msg, strlen(msg), HAL_MAX_DELAY);



	/* Start receiving data via DMA (circular mode) */
//	HAL_UART_Receive_DMA(&huart7, rx_buffer, 8);

	for(;;)
	{
		if (osMutexAcquire(g_axesMutex, 10) == osOK)
		{
			for(int i = 0; i < 8; i++)
			{
				g_axes[i] = (g_axes[i] + 1) % 10;
			}
			osMutexRelease(g_axesMutex);
		}
		osDelay(5000);
	}
}

/* Reception Complete Callback (for NORMAL mode) */
void HAL_UART_RxCpltCallback(UART_HandleTypeDef *huart)
{
    if (huart->Instance == USART2)
    {
        // This is called when using DMA_NORMAL mode
        // With DMA_CIRCULAR, this isn't called
        rx_complete = 1;

        // Restart reception for next 8 bytes
        HAL_UART_Receive_DMA(&huart7, rx_buffer, 8);
    }
}

/* USER CODE END 4 */

/* USER CODE BEGIN Header_StartDefaultTask */
/**
  * @brief  Function implementing the defaultTask thread.
  * @param  argument: Not used
  * @retval None
  */
/* USER CODE END Header_StartDefaultTask */
void StartDefaultTask(void *argument)
{
  /* USER CODE BEGIN 5 */
  /* Infinite loop */
  for(;;)
  {


	  osDelay(100);
  }
  /* USER CODE END 5 */
}

 /* MPU Configuration */

void MPU_Config(void)
{
  MPU_Region_InitTypeDef MPU_InitStruct = {0};

  /* Disables the MPU */
  HAL_MPU_Disable();

  /** Initializes and configures the Region and the memory to be protected
  */
  MPU_InitStruct.Enable = MPU_REGION_ENABLE;
  MPU_InitStruct.Number = MPU_REGION_NUMBER0;
  MPU_InitStruct.BaseAddress = 0x90000000;
  MPU_InitStruct.Size = MPU_REGION_SIZE_256MB;
  MPU_InitStruct.SubRegionDisable = 0x0;
  MPU_InitStruct.TypeExtField = MPU_TEX_LEVEL0;
  MPU_InitStruct.AccessPermission = MPU_REGION_FULL_ACCESS;
  MPU_InitStruct.DisableExec = MPU_INSTRUCTION_ACCESS_ENABLE;
  MPU_InitStruct.IsShareable = MPU_ACCESS_NOT_SHAREABLE;
  MPU_InitStruct.IsCacheable = MPU_ACCESS_NOT_CACHEABLE;
  MPU_InitStruct.IsBufferable = MPU_ACCESS_NOT_BUFFERABLE;

  HAL_MPU_ConfigRegion(&MPU_InitStruct);

  /** Initializes and configures the Region and the memory to be protected
  */
  MPU_InitStruct.Number = MPU_REGION_NUMBER1;
  MPU_InitStruct.Size = MPU_REGION_SIZE_16MB;
  MPU_InitStruct.IsCacheable = MPU_ACCESS_CACHEABLE;

  HAL_MPU_ConfigRegion(&MPU_InitStruct);
  /* Enables the MPU */
  HAL_MPU_Enable(MPU_PRIVILEGED_DEFAULT);

}

/**
  * @brief  Period elapsed callback in non blocking mode
  * @note   This function is called  when TIM6 interrupt took place, inside
  * HAL_TIM_IRQHandler(). It makes a direct call to HAL_IncTick() to increment
  * a global variable "uwTick" used as application time base.
  * @param  htim : TIM handle
  * @retval None
  */
void HAL_TIM_PeriodElapsedCallback(TIM_HandleTypeDef *htim)
{
  if (htim->Instance == TIM6)
  {
    HAL_IncTick();
  }
}

/**
  * @brief  This function is executed in case of error occurrence.
  * @retval None
  */
void Error_Handler(void)
{
  /* USER CODE BEGIN Error_Handler_Debug */
  /* User can add his own implementation to report the HAL error return state */

  /* USER CODE END Error_Handler_Debug */
}
#ifdef USE_FULL_ASSERT
/**
  * @brief  Reports the name of the source file and the source line number
  *         where the assert_param error has occurred.
  * @param  file: pointer to the source file name
  * @param  line: assert_param error line source number
  * @retval None
  */
void assert_failed(uint8_t *file, uint32_t line)
{
  /* USER CODE BEGIN 6 */
  /* User can add his own implementation to report the file name and line number,
     tex: printf("Wrong parameters value: file %s on line %d\r\n", file, line) */
  /* USER CODE END 6 */
}
#endif /* USE_FULL_ASSERT */

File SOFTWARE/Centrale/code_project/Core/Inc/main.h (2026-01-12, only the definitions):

#define VSYNC_FREQ_Pin GPIO_PIN_4
#define VSYNC_FREQ_GPIO_Port GPIOB
#define LCD_BL_CTRL_Pin GPIO_PIN_3
#define LCD_BL_CTRL_GPIO_Port GPIOK
#define LCD_DISP_Pin GPIO_PIN_12
#define LCD_DISP_GPIO_Port GPIOI
#define FRAME_RATE_Pin GPIO_PIN_7
#define FRAME_RATE_GPIO_Port GPIOC
#define RENDER_TIME_Pin GPIO_PIN_6
#define RENDER_TIME_GPIO_Port GPIOC
#define MCU_ACTIVE_Pin GPIO_PIN_6
#define MCU_ACTIVE_GPIO_Port GPIOG

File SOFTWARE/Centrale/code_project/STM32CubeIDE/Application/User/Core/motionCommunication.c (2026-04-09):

#include "motionCommunication.h"

static UART_HandleTypeDef *p_huart = NULL;

// Shared value with extern c files (motionState.c)
CommState_t commState = COMM_STATE_IDLE;


// Global control variables

static uint8_t currentSlaveIdx = 0;
static uint8_t retryCount = 0;
static uint32_t lastRequestTick = 0;

MotionPacket_t txPacket;
MotionPacket_t rxPacket;
uint8_t rxBuffer[sizeof(MotionPacket_t)];

// Helper to map index to address
static const uint8_t slaveAddresses[] = {ADDRESSPISTONTL, ADDRESSPISTONTR, ADDRESSPISTONBL, ADDRESSPISTONBR};



static int cycleCount = 0;
static int targetCycles = 0;

void motionComm_Init(UART_HandleTypeDef *huart_instance) {
    p_huart = huart_instance;
}


void startCommunicationCycle(void) {
    currentSlaveIdx = 0;
    retryCount = 0;
    commState = COMM_STATE_WAITING_FOR_RX;
    sendRequestToSlave(slaveAddresses[currentSlaveIdx]);
}

void sendRequestToSlave(uint8_t address) {
    memset(&txPacket, 0, sizeof(MotionPacket_t));
    txPacket.address = address;
    txPacket.statusFlags = FLAGM_AWN_REQUEST;

    // Flush RX DMA memory bfeore transmission
    HAL_UART_AbortReceive(p_huart);
    HAL_UARTEx_ReceiveToIdle_DMA(p_huart, rxBuffer, sizeof(MotionPacket_t));

    // transmitPacket(huart, &txPacket);
    lastRequestTick = HAL_GetTick();
}

void processCommunicationManager(void) {
    switch (commState) {
        case COMM_STATE_WAITING_FOR_RX:
            // Check for Hardware Timeout
            if ((HAL_GetTick() - lastRequestTick) > TIMEOUT_MS) {
                handleCommError();
            }
            break;

        case COMM_STATE_PROCESSING:
            // 1. Process data from previous slave (already stored in rxPacket)
        	handlePacket(&rxPacket);

            // 2. Move to next slave
            currentSlaveIdx++;
            if (currentSlaveIdx >= 4) {
                currentSlaveIdx = 0; // Cycle complete
                commState = COMM_STATE_IDLE;
            } else {
                retryCount = 0;
                commState = COMM_STATE_WAITING_FOR_RX;
                sendRequestToSlave(slaveAddresses[currentSlaveIdx]);
            }
            break;

        case COMM_STATE_FAILURE:
            // System-level error handling (e.g., enter MASTER_STATE_ERROR) [TO DO]
            break;

        default:
            break;
    }
}


void handleCommError(void) {
    if (retryCount < MAX_RETRIES) {
        retryCount++;
        sendRequestToSlave(slaveAddresses[currentSlaveIdx]);
    } else {
        // LINK: If retries fail, trigger the Global Error FSM
        commState = COMM_STATE_FAILURE;
        triggerGlobalError(ERR_COMM_LOST, STATE_IDLE, NULL);
    }
}


void HAL_UARTEx_RxEventCallback(UART_HandleTypeDef *huart, uint16_t Size) {
    if(huart == p_huart && p_huart != NULL) {
        MotionPacket_t *received = (MotionPacket_t*)rxBuffer;
        uint8_t calc = calculateChecksum(received);

        if (Size >= sizeof(MotionPacket_t) && calc == received->checksum) {
            // Update Health Table for this specific slave
            uint8_t idx = received->address; // Assuming address 0-3
            Health_Update(idx, received);
            // systemHealth[idx].errorCount = 0;

            memcpy(&rxPacket, received, sizeof(MotionPacket_t));
            commState = COMM_STATE_PROCESSING;
        } else {
            handleCommError();
        }
    }
}

void comm_RequestAction(motionState_t mode, int param) {
    currentSlaveIdx = 0;
    retryCount = 0;
    cycleCount = 0;
    targetCycles = param;

    // Map Motion States to Comm States
    if (mode == STATE_PINGING) {
        commState = COMM_STATE_WAITING_FOR_RX;
        txPacket = pingPacketStructure;
        sendRequestToSlave(slaveAddresses[currentSlaveIdx]);
    } else {
        commState = COMM_STATE_PROCESSING;
    }
}

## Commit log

2025-11-05 Driver code for graphic and volatile memory
2025-11-05 Create driver repo
2025-11-05 addition of STM32 IDE configuration of the prject
2025-11-09 PCB v2
    Schematic
    [Ampli.kicad_sch, CSD18510Q5B.stp, Driver_FOC_v1.kicad_pcb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]
2025-11-17 Routage Phases PCB
    [Ampli.kicad_sch, CSD19534Q5AT.stp, DeBouton.stp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]
2025-11-18 Routage PCB 99%
    [FOC_CONTROLLER_V2.kicad_pcb, FOC_CONTROLLER_V2.kicad_sch]
2025-11-25 no more FOC_CONTROLLER_V2 directory
    Plus de hardware dans le software
    [Ampli.kicad_sch, CSD18510Q5B.stp, CSD19534Q5AT.stp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]
2025-12-11 Fix image filename case in README.md
2026-01-13 Repo hardware rework
    [Ampli.kicad_sch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]
2026-01-16 Enlever le texte fais par gemini (IA) dans le readme
    Je me demande si les profs vont regarder tous les commit. j'espere pas.
2026-04-09 Bouger des fichiers
2026-04-09 Bouger des fichiers2
2026-04-10 Driver readme 1
2026-04-10 Driver readme 2
2026-04-10 Driver readme 3
2026-04-10 Driver readme 4
2026-04-10 Driver readme 5
2026-04-10 Driver readme 6

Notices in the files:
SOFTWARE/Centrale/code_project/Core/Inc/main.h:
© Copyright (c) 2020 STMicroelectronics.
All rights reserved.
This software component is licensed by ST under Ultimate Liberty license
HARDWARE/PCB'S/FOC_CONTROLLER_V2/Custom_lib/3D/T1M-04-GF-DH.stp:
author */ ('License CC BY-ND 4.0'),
